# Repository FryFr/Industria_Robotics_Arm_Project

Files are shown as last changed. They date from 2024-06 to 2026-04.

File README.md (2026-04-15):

# 🦾 6-DoF Industrial Robotic Arm — Design, Simulation & Control

<div align="center">










**Full-pipeline research project for the design, 3D modeling, kinematic analysis, ROS simulation, and physical construction of a 6-Degrees-of-Freedom robotic arm with a gear-actuated gripper, capable of object pick-and-place operations.**

[Kinematic Model](#-kinematic-model--denavit-hartenberg-analysis) · [URDF Specification](#-urdf-model-specification) · [Arduino Control](#-arduino-control-system) · [Simulation](#-ros--gazebo-simulation) · [Hardware](#-hardware-components) · [Repository Structure](#-repository-structure)

</div>

---

## 📋 Table of Contents

- [Project Overview](#-project-overview)
- [Academic Context](#-academic-context)
- [System Architecture](#-system-architecture)
- [Mechanical Design — SolidWorks](#-mechanical-design--solidworks)
- [Physical Components Breakdown](#-physical-components-breakdown)
- [Kinematic Model — Denavit-Hartenberg Analysis](#-kinematic-model--denavit-hartenberg-analysis)
- [URDF Model Specification](#-urdf-model-specification)
- [Joint Parameters & Motion Limits](#-joint-parameters--motion-limits)
- [Link Inertial Properties](#-link-inertial-properties)
- [Gripper Mechanism](#-gripper-mechanism)
- [ROS & Gazebo Simulation](#-ros--gazebo-simulation)
- [Arduino Control System](#-arduino-control-system)
- [PCA9685 PWM Servo Driver](#-pca9685-pwm-servo-driver)
- [Control Sequence & Automation](#-control-sequence--automation)
- [Inverse Kinematics](#-inverse-kinematics)
- [Hardware Components](#-hardware-components)
- [Repository Structure](#-repository-structure)
- [Setup & Installation](#-setup--installation)
- [Roadmap](#-roadmap)
- [Contributing](#-contributing)
- [Author](#-author)
- [License](#-license)

---

## 🤖 Project Overview

This repository contains the complete engineering deliverables for the design, simulation, and physical construction of a **6-Degrees-of-Freedom (6-DoF) robotic manipulator arm** equipped with a gear-actuated parallel gripper. The project spans the full development pipeline:

1. **CAD modeling** — Each structural component was individually modeled in SolidWorks, with formal engineering drawings and PDF documentation
2. **Kinematic analysis** — Forward kinematics derived using the Denavit-Hartenberg (DH) convention; inverse kinematics formulated analytically
3. **URDF generation** — The SolidWorks assembly was exported to URDF format using the `sw_urdf_exporter` plugin, preserving mesh geometry, inertial tensors, joint axes, and motion limits
4. **ROS simulation** — The URDF model is integrated into ROS with launch files for both RViz visualization and Gazebo physics simulation
5. **Embedded control** — An Arduino UNO + PCA9685 system drives 5 servomotors over I2C with a serial-command automation interface

The arm is designed for **pick-and-place operations** on objects at known workspace locations, controlled via predefined joint-space trajectories.

URDF Visualization

---

## 🎓 Academic Context

| Field | Detail |
|---|---|
| **Course** | Robotics |
| **Institution** | Universidad EAN |
| **Supervisor** | Prof. Nikolay Prieto, Ph.D. |
| **Submission Date** | June 10th, 2024 |
| **Project Type** | Research & Engineering Final Project |

---

## 🏗 System Architecture

```
┌────────────────────────────────────────────────────────────────────┐
│                      FULL SYSTEM PIPELINE                          │
│                                                                    │
│  ┌──────────────┐    ┌──────────────┐    ┌──────────────────────┐  │
│  │  SolidWorks  │───▶│ URDF Export  │───▶│   ROS / Gazebo       │  │
│  │  CAD Model   │    │ sw_urdf v1.6 │    │  RViz + MoveIt       │  │
│  └──────────────┘    └──────────────┘    └──────────────────────┘  │
│                                                                    │
│  ┌──────────────┐    ┌──────────────┐    ┌──────────────────────┐  │
│  │  DH Analysis │───▶│  Kinematics  │───▶│   Joint Trajectories │  │
│  │  (Forward)   │    │  (Inverse)   │    │   & Path Planning    │  │
│  └──────────────┘    └──────────────┘    └──────────────────────┘  │
│                                                                    │
│  ┌──────────────┐    ┌──────────────┐    ┌──────────────────────┐  │
│  │  Arduino UNO │───▶│   PCA9685    │───▶│  5× Servo Motors     │  │
│  │  Serial I/O  │    │  I2C PWM     │    │  MG996R + SG90       │  │
│  └──────────────┘    └──────────────┘    └──────────────────────┘  │
└────────────────────────────────────────────────────────────────────┘
```

---

## 🔩 Mechanical Design — SolidWorks

The mechanical design phase used **SolidWorks** to model every structural component from scratch, producing precise digital models that served as manufacturing inputs for 3D printing.

### Individual Part Inventory

| SolidWorks Part | URDF Link | Physical Role |
|---|---|---|
| `BaseCentral.SLDPRT` | `base_link` | Fixed base, anchors the full kinematic chain |
| `Hombro.SLDPRT` | `Link_1` | Shoulder — full 360° rotation on vertical axis |
| `Brazo.SLDPRT` | `Link_2` | Upper arm — elevation from shoulder |
| `Codo.SLDPRT` | `Link_3` | Elbow — bends arm toward target |
| `Mano1.SLDPRT` | `Link_4` | Wrist roll — full 360° rotation |
| `Mano2.SLDPRT` | `Link_5` | Wrist pitch — orients end-effector |
| `Gripper base mano3.SLDPRT` | `Link_6` | Gripper mount — connects wrist to gripper |
| `gear1.SLDPRT` | `Gear_1` | Gripper drive gear — left finger actuator |
| `gear2.SLDPRT` | `Gear_2` | Gripper driven gear — right finger actuator |
| `Gripper 1.SLDPRT` | — | Finger structure |
| `grip link 1.SLDPRT` | — | Finger linkage |
| `Servo Motor MG996R.SLDPRT` | — | High-torque joint actuator (modeled) |
| `Servo Motor Micro 9g.SLDPRT` | — | Lightweight joint actuator (modeled) |

### Assembly Files

| Assembly | Contents |
|---|---|
| `Ensamble.SLDASM` | Primary arm assembly (base to wrist) |
| `Ensamble2.SLDASM` | Full assembly including gripper |
| `EnsamblePinza.SLDASM` | Isolated gripper sub-assembly with gears |

### Engineering Drawings

All parts have formal 2D engineering drawings available in two formats:

- **SolidWorks Drawings** (`.SLDDRW`) — Full parametric drawings with dimensions, tolerances and views
- **PDF Drawings** — Exported static drawings for reference and printing

Available drawings: `BaseCentral`, `Brazo`, `Codo`, `Hombro`, `Mano1`, `Mano2`, `gear1`, `gear2`, `Gripper 1`, `Gripper base mano3`, `grip link 1`, `Ensamble1_brazo` (sub-assembly), `Ensamble_explosionado_robot` (exploded view of full robot).

> 🔧 The exploded view (`Ensamble_explosionado_robot.pdf`) is particularly useful for understanding assembly order and fastener placement.

### 3D Printing

All structural parts were manufactured using **FDM (Fused Deposition Modeling) 3D printing** with **PLA (Polylactic Acid)** filament. PLA was selected for its:
- Low warping during printing
- Sufficient structural rigidity for low-load robotic applications
- Ease of post-processing
- Biodegradable properties

The SolidWorks parts were exported to STL format (the same STL meshes used in the URDF), ensuring dimensional consistency between the CAD model, the simulation, and the physical prototype.

Physical Assembly

---

## 📐 Kinematic Model — Denavit-Hartenberg Analysis

The forward kinematics of the arm were derived using the **Denavit-Hartenberg (DH) convention**, which provides a systematic 4-parameter representation of the transformation between consecutive joint frames.

### Why DH over Trigonometric Analysis?

Trigonometric position equations and direct Cartesian formulations are viable for 2- or 3-DoF systems. However, for a 6-DoF manipulator, the complexity of coupled rotations and translations makes these approaches intractable. The DH convention reduces each inter-frame transformation to a product of four elementary operations:

```
T(i-1→i) = Rot_z(θᵢ) · Trans_z(dᵢ) · Trans_x(aᵢ) · Rot_x(αᵢ)
```

Where:
- **θᵢ** — joint angle (rotation around z-axis, variable for revolute joints)
- **dᵢ** — link offset (translation along z-axis)
- **aᵢ** — link length (translation along x-axis)
- **αᵢ** — link twist (rotation around x-axis)

### DH Frame Assignment Convention

1. Frame 0 was fixed to the world/base and assigned to the first joint axis
2. Subsequent frames (1–6) were positioned following the DH rules, strictly avoiding pure rotations or translations about the Y-axis (which would require a modified DH formulation)
3. The final frame (Frame 6) coincides with the end-effector at the gripper center

### DH Table

Based on the URDF joint origins and axes, the DH parameters for the 6 main joints are:

| Joint | θᵢ (variable) | dᵢ (m) | aᵢ (m) | αᵢ (rad) | Type |
|---|---|---|---|---|---|
| Joint_1 | θ₁ | 0.0465 | 0.0308 | 0 | Revolute |
| Joint_2 | θ₂ | 0.1150 | 0.0011 | π/2 | Revolute |
| Joint_3 | θ₃ | 0 | 0.1000 | 0 | Revolute |
| Joint_4 | θ₄ | 0.0818 | 0.0001 | -π/2 | Revolute |
| Joint_5 | θ₅ | 0.0215 | 0 | -π/2 | Revolute |
| Joint_6 | θ₆ | 0 | 0.0350 | -π/2 | Revolute |

> Values extracted from URDF joint `<origin>` tags. The full homogeneous transformation matrix T(0→6) = T₁ · T₂ · T₃ · T₄ · T₅ · T₆ gives the end-effector pose in the base frame.

### Forward Kinematics

The full forward kinematic chain resolves to:

```
T(base→EE) = T₁(θ₁) × T₂(θ₂) × T₃(θ₃) × T₄(θ₄) × T₅(θ₅) × T₆(θ₆)
```

This yields a **4×4 homogeneous transformation matrix** encoding the end-effector position (x, y, z) and orientation (R₃ₓ₃ rotation matrix) in the world frame.

DH Frame Diagram

---

## 📄 URDF Model Specification

The URDF was automatically generated from the SolidWorks assembly using the **`sw_urdf_exporter` plugin v1.6.0-4-g7f85cfe (Build 1.6.7995.38578)** by Stephen Brawner.

The model file is located at:
```
1.Software/Ensamblaje_urdf/urdf/Ensamblaje_urdf.urdf
```

### Link Tree

```
base_link
└── Link_1        (Joint_1  — revolute, z-axis)
    └── Link_2    (Joint_2  — revolute, z-axis, limited ±30°)
        └── Link_3  (Joint_3 — revolute, z-axis)
            └── Link_4  (Joint_4 — revolute, z-axis, full)
                └── Link_5  (Joint_5 — revolute, z-axis)
                    └── Link_6  (Joint_6 — revolute, z-axis, full)
                        ├── Gear_1  (joint_gear1 — revolute, y-axis, ±30°)
                        └── Gear_2  (Joint_gear2 — revolute, y-axis, ±30°)
```

### STL Mesh Files

All meshes reside in `1.Software/Ensamblaje_urdf/meshes/`:

| Mesh File | Link | Approx. Size |
|---|---|---|
| `base_link.STL` | base_link | 108 KB |
| `Link_1.STL` | Link_1 (Shoulder) | 114 KB |
| `Link_2.STL` | Link_2 (Upper arm) | 104 KB |
| `Link_3.STL` | Link_3 (Elbow) | 54 KB |
| `Link_4.STL` | Link_4 (Wrist roll) | 55 KB |
| `Link_5.STL` | Link_5 (Wrist pitch) | 23 KB |
| `Link_6.STL` | Link_6 (Gripper mount) | 33 KB |
| `Gear_1.STL` | Gear_1 (Left gripper) | 69 KB |
| `Gear_2.STL` | Gear_2 (Right gripper) | 64 KB |

All meshes use the visual/collision color `rgba(0.792, 0.820, 0.933, 1.0)` — a light steel blue.

---

## 📊 Joint Parameters & Motion Limits

The following table consolidates all joint data extracted directly from the URDF:

| Joint | Type | Parent → Child | Origin (x, y, z) m | Origin (r, p, y) rad | Axis | Lower (rad) | Upper (rad) | Range (°) | Friction |
|---|---|---|---|---|---|---|---|---|---|
| `Joint_1` | revolute | base → Link_1 | (0.031, -0.097, 0.047) | (0, 0, π/2) | Z | -3.141 | 3.141 | 360° | 0.1 |
| `Joint_2` | revolute | Link_1 → Link_2 | (-0.001, -0.019, 0.115) | (π/2, 0, -0.057) | Z | -0.524 | 0.524 | 60° | 0.1 |
| `Joint_3` | revolute | Link_2 → Link_3 | (0, 0.100, 0) | (0, 0, π/2) | Z | -1.570 | 0.349 | 110° | 0.1 |
| `Joint_4` | revolute | Link_3 → Link_4 | (0.000, 0.082, 0.006) | (-π/2, 0, 0) | Z | -3.141 | 3.141 | 360° | 0.1 |
| `Joint_5` | revolute | Link_4 → Link_5 | (0, -0.008, 0.022) | (-π/2, 0, -π) | Z | -3.141 | 0.174 | 190° | 0.1 |
| `Joint_6` | revolute | Link_5 → Link_6 | (0.035, -0.000, -0.008) | (-π/2, 0, -π/2) | Z | -3.141 | 3.141 | 360° | 0.1 |
| `joint_gear1` | revolute | Link_6 → Gear_1 | (-0.014, 0.002, 0.023) | (0, 0, 0) | Y | -0.523 | 0.523 | 60° | — |
| `Joint_gear2` | revolute | Link_6 → Gear_2 | (0.013, -0.003, 0.023) | (0, 0, 0) | Y | -0.523 | 0.523 | 60° | — |

### Total Workspace DoF

- **6 active joints** (Joint_1 through Joint_6) — full arm positioning and orientation
- **2 gripper joints** (joint_gear1 + Joint_gear2) — parallel gear-actuated gripper
- **Total: 8 revolute joints** in the kinematic chain

### Servo-to-Joint Mapping (Physical)

| PCA9685 Channel | Physical Joint | SolidWorks Link | Servo Model | Angle Limit |
|---|---|---|---|---|
| Servo 0 | Base rotation | base_link ↔ Link_1 | MG996R | 0° – 180° |
| Servo 1 | Shoulder elevation | Link_1 ↔ Link_2 | MG996R | 0° – 85° |
| Servo 2 | Elbow flex | Link_2 ↔ Link_3 | MG996R | 0° – 90° |
| Servo 3 | Wrist pitch | Link_3 ↔ Link_4 | SG90 | 2° – 90° |
| Servo 4 | Gripper open/close | Gear_1 + Gear_2 | SG90 | 0° – 80° |

---

## ⚖️ Link Inertial Properties

Inertial data was computed directly by SolidWorks from the PLA density and exported to the URDF. These values are used by Gazebo for realistic physics simulation.

| Link | Mass (kg) | CoM X (m) | CoM Y (m) | CoM Z (m) | Ixx (kg·m²) | Iyy (kg·m²) | Izz (kg·m²) |
|---|---|---|---|---|---|---|---|
| base_link | 0.09282 | 0.03222 | -0.09726 | 0.06830 | 1.236e-4 | 1.267e-4 | 2.077e-4 |
| Link_1 | 0.10004 | 0.00279 | -0.01420 | 0.07333 | 1.228e-4 | 1.201e-4 | 1.071e-4 |
| Link_2 | 0.03836 | 0.00023 | 0.04485 | -0.00621 | 4.759e-5 | 5.827e-6 | 5.167e-5 |
| Link_3 | 0.02286 | 0.00070 | 0.02860 | 0.00472 | 1.938e-5 | 4.279e-6 | 2.256e-5 |
| Link_4 | 0.01138 | ~0 | -0.01420 | 0.00948 | 2.517e-6 | 2.816e-6 | 1.653e-6 |
| Link_5 | 0.01079 | 0.02085 | -0.00257 | -0.00310 | 1.978e-6 | 2.552e-6 | 3.258e-6 |
| Link_6 | 0.01024 | -0.00420 | 0.00847 | 0.01757 | 1.703e-6 | 3.123e-6 | 1.667e-6 |
| Gear_1 | 0.00933 | -0.01598 | 0.00255 | 0.02202 | 1.711e-6 | 2.285e-6 | 6.491e-7 |
| Gear_2 | 0.00938 | 0.01667 | 0.00652 | 0.02210 | 1.730e-6 | 2.285e-6 | 6.304e-7 |
| **Total** | **~0.336 kg** | — | — | — | — | — | — |

> The **total estimated arm mass is ~336 g**, consistent with a lightweight 3D-printed PLA prototype. Link_1 (Shoulder) is the heaviest link at 100 g.

---

## 🤏 Gripper Mechanism

The end-effector is a **gear-actuated parallel gripper** using a spur gear pair to synchronize the opening and closing of two finger assemblies:

### Gear Pair Specification

| Parameter | Gear_1 | Gear_2 |
|---|---|---|
| Parent Link | Link_6 | Link_6 |
| Origin offset | (-0.0139, 0.0015, 0.0225) | (0.013, -0.0025, 0.0225) |
| Rotation axis | Y | Y |
| Motion range | ±0.523 rad (±30°) | ±0.523 rad (±30°) |
| Mass | 9.33 g | 9.38 g |

### Gripper Sub-Assembly Components

The `EnsamblePinza.SLDASM` sub-assembly contains:
- `Gripper base mano3` — palm/base plate connecting to Link_6
- `Gripper 1` (×2) — finger bodies
- `grip link 1` (×4) — four-bar linkage elements connecting gears to fingers
- `gear1` + `gear2` — mating spur gear pair

The four-bar linkage mechanism converts the ±30° gear rotation into a symmetric lateral motion of both fingers, enabling **parallel jaw grasping**.

---

## 🖥 ROS & Gazebo Simulation

### Software Requirements

| Package | Version | Purpose |
|---|---|---|
| Ubuntu | 20.04 LTS | Operating system |
| ROS | Noetic (ROS 1) | Robot middleware and launch system |
| Gazebo | 11 | Physics simulation |
| RViz | 1.14+ | 3D visualization |
| `robot_state_publisher` | — | Broadcasts joint transforms (TF) |
| `joint_state_publisher_gui` | — | Interactive joint sliders in RViz |
| `sw_urdf_exporter` | 1.6.0 | SolidWorks → URDF export plugin |

> ⚠️ **Note:** The launch files use **ROS 1 (Noetic)** syntax (`roslaunch`, `<node pkg="...">`, `$(find ...)`). Despite references to ROS2 in the project documentation, the actual launch infrastructure is ROS 1.

### ROS Package Setup

```bash
# Create and build the workspace
mkdir -p ~/catkin_ws/src
cd ~/catkin_ws/src
# Copy the Ensamblaje_urdf package here
cp -r /path/to/Industria_Robotics_Arm_Project/1.Software/Ensamblaje_urdf .

cd ~/catkin_ws
catkin_make
source devel/setup.bash
```

### Launch — RViz Visualization

Visualize the arm with interactive joint sliders:

```bash
roslaunch Ensamblaje_urdf display.launch
```

This launches:
- `joint_state_publisher_gui` — GUI sliders for manually commanding each joint angle
- `robot_state_publisher` — Computes and broadcasts all link TF transforms from joint states
- `rviz` — 3D visualization with the robot model loaded

### Launch — Gazebo Physics Simulation

Spawn the arm in an empty Gazebo world:

```bash
roslaunch Ensamblaje_urdf gazebo.launch
```

This launches:
- `gazebo` (empty world)
- `spawn_model` — loads the URDF into Gazebo via `gazebo_ros`
- `tf_footprint_base` — static TF between `base_link` and `base_footprint`
- `fake_joint_calibration` — publishes `/calibrated` to unblock joint controllers

### Joint Names Configuration

The controller joint list is defined in `config/joint_names_Ensamblaje_urdf.yaml`:

```yaml
controller_joint_names: [
  '',           # placeholder
  'Joint_1',    # Shoulder rotation
  'Joint_2',    # Upper arm elevation
  'Joint_3',    # Elbow flexion
  'Joint_4',    # Wrist roll
  'Joint_5',    # Wrist pitch
  'Joint_6',    # End-effector rotation
  'joint_gear1', # Gripper left
  'Joint_gear2'  # Gripper right
]
```

### URDF Validation

Before launching, validate the URDF for kinematic and XML errors:

```bash
# Check URDF structure
check_urdf 1.Software/Ensamblaje_urdf/urdf/Ensamblaje_urdf.urdf

# Visualize link tree
urdf_to_graphiz 1.Software/Ensamblaje_urdf/urdf/Ensamblaje_urdf.urdf
evince Ensamblaje_urdf.pdf
```

---

## 🎮 Arduino Control System

### Architecture

```
PC / Host
   │
   │  Serial (USB, 9600 baud)
   ▼
Arduino UNO
   │
   │  I2C (SDA/SCL — pins A4/A5)
   ▼
PCA9685 (16-ch PWM Driver @ 0x40)
   │
   ├── Ch 0 — MG996R — Base rotation
   ├── Ch 1 — MG996R — Shoulder elevation
   ├── Ch 2 — MG996R — Elbow flexion
   ├── Ch 3 — SG90  — Wrist pitch
   └── Ch 4 — SG90  — Gripper
```

### Core Control Code — `Manual_Control.ino`

```cpp
#include <Wire.h>
#include <Adafruit_PWMServoDriver.h>

Adafruit_PWMServoDriver pwm;

// PWM pulse width range for servo control (in 12-bit counts @ 60 Hz)
const int SERVOMIN = 150;  // ~0.7 ms pulse  → 0°
const int SERVOMAX = 600;  // ~2.4 ms pulse  → 180°
```

### PWM Frequency & Pulse Width

The PCA9685 is configured at **60 Hz**, which is the standard PWM frequency for analog servomotors. The `SERVOMIN` and `SERVOMAX` counts correspond to:

```
Pulse width (µs) = count × (1 / (60 Hz × 4096)) × 10⁶
SERVOMIN (150) → 150 / (60 × 4096) × 1e6 ≈ 610 µs
SERVOMAX (600) → 600 / (60 × 4096) × 1e6 ≈ 2441 µs
```

The angle-to-pulse mapping:

```cpp
int pulseLength = map(angle, 0, 180, SERVOMIN, SERVOMAX);
pwm.setPWM(servo, 0, pulseLength);
```

---

## 🔧 PCA9685 PWM Servo Driver

The **PCA9685** is a 16-channel, 12-bit PWM driver from NXP/Adafruit that communicates over I2C. It offloads all servo timing from the Arduino, allowing deterministic PWM signals on up to 16 channels simultaneously.

| Parameter | Value |
|---|---|
| Communication | I2C (default address `0x40`) |
| Channels | 16 |
| Resolution | 12-bit (4096 steps per cycle) |
| PWM Frequency | Configurable 40–1000 Hz (set to 60 Hz) |
| Arduino Pins | SDA → A4, SCL → A5 |
| Library | `Adafruit_PWMServoDriver` |
| Operating Voltage | 3.3V or 5V logic; servo power separate (V+) |

> ⚠️ **Important:** The PCA9685 V+ rail must be connected to an **external 5–6V DC power supply**, not the Arduino 5V pin. The MG996R servos draw up to 2.5A stall current each — powering them from the Arduino will cause brownouts and undefined behavior.

### I2C Wiring

```
Arduino UNO     PCA9685
-----------     -------
A4 (SDA)   ──── SDA
A5 (SCL)   ──── SCL
5V         ──── VCC (logic)
GND        ──── GND
           ──── V+  ←── External 5V supply (+)
           ──── GND ←── External 5V supply (-)
```

---

## 🔄 Control Sequence & Automation

The firmware implements a **serial-triggered state machine**. The user sends single-character commands via the Serial Monitor:

| Command | Action |
|---|---|
| `Y` or `y` | Start pick-and-place automation sequence |
| `S` or `s` | Stop and hold current position |

### Predefined Motion Sequence

The `executeSequence()` function defines three joint-space waypoints:

```
POSITION 1 — Home (Initial)
   Servo 0: 90°  (base centered)
   Servo 1:  0°  (shoulder down)
   Servo 2:  0°  (elbow straight)
   Servo 3:  2°  (wrist neutral)
   Servo 4: 80°  (gripper open)

POSITION 2 — Object Pickup
   Servo 0: 90°  (base centered)
   Servo 1: 45°  (shoulder mid-elevation)
   Servo 2: 45°  (elbow bent)
   Servo 3: 45°  (wrist angled)
   Servo 4:  0°  (gripper closed → grips object)

POSITION 3 — Destination
   Servo 0: 150° (base rotated to drop zone)
   Servo 1: 20°  (shoulder lowered)
   Servo 2: 20°  (elbow extended)
   Servo 3: 20°  (wrist adjusted)
   Servo 4: 80°  (gripper open → releases object)

→ Returns to POSITION 1 (Home)
```

Each position is held for **1000 ms** before transitioning to the next waypoint.

### Per-Joint Angle Limits (Firmware)

These software limits are enforced independently of the hardware/URDF limits:

| Channel | Joint | Min (°) | Max (°) | Notes |
|---|---|---|---|---|
| 0 | Base | 0 | 180 | Full servo range |
| 1 | Shoulder | 0 | 85 | Mechanically constrained |
| 2 | Elbow | 0 | 90 | Mechanically constrained |
| 3 | Wrist pitch | 2 | 90 | Offset to avoid singularity at 0° |
| 4 | Gripper | 0 | 80 | 0° = closed, 80° = open |

---

## 🧮 Inverse Kinematics

The `1.Software/Invers_Kinematics/` directory is reserved for inverse kinematics computation. The analytical IK problem for a 6-DoF spherical-wrist manipulator can be decoupled into:

1. **Positional IK** (Joints 1–3): Determines the shoulder, elbow, and base angles to position the wrist center at the desired 3D location
2. **Orientational IK** (Joints 4–6): Determines the wrist Euler angles to achieve the desired end-effector orientation

### Analytical Approach (Spherical Wrist Decoupling)

For a robot with a spherical wrist (Joints 4, 5, 6 intersecting at a single point), the IK decouples as:

```
Step 1 — Compute wrist center position:
   Pw = Pd - d₆ · R_desired · [0, 0, 1]ᵀ

Step 2 — Solve for θ₁, θ₂, θ₃ geometrically:
   θ₁ = atan2(Pw_y, Pw_x)
   Use law of cosines for θ₂, θ₃ given link lengths a₂, a₃

Step 3 — Solve for θ₄, θ₅, θ₆:
   R₃₆ = (R₀₃)ᵀ · R_desired
   Extract Euler angles from R₃₆
```

> 📌 **Note:** The `Invers_Kinematics/Sample.txt` placeholder indicates this module is planned for future implementation. Contributions implementing the analytical IK are welcome — see [Contributing](#-contributing).

---

## 🧰 Hardware Components

| Component | Model | Qty | Role |
|---|---|---|---|
| Microcontroller | Arduino UNO | 1 | Main controller, serial interface |
| PWM Driver | PCA9685 (Adafruit) | 1 | 16-channel I2C servo controller |
| High-torque servo | MG996R | 3 | Joints 0–2 (base, shoulder, elbow) |
| Micro servo | SG90 (9g) | 2 | Joints 3–4 (wrist, gripper) |
| DC Power Supply | 5–6V, 3A+ | 1 | Servo power (external) |
| PLA Filament | 1.75mm PLA | ~250g | 3D printing all structural parts |
| Fasteners | M2/M3 screws+nuts | Assorted | Part assembly |
| Jumper wires | M-M, M-F | ~20 | Electronic connections |
| Protoboard | Full-size | 1 | Component layout |

### Servo Comparison

| Spec | MG996R | SG90 |
|---|---|---|
| Stall Torque | 9.4 kg·cm (6V) | 1.8 kg·cm (5V) |
| Operating Voltage | 4.8–7.2V | 4.8–6V |
| Speed | 0.19 s/60° | 0.1 s/60° |
| Weight | 55 g | 9 g |
| Gear Type | Metal | Plastic/nylon |
| Use in project | Primary joints (high load) | Wrist + gripper (low load) |

---

## 📁 Repository Structure

```
Industria_Robotics_Arm_Project/
│
├── 0.Model/
│   ├── 0.0. Individual Parts/          # SolidWorks part files (.SLDPRT)
│   │   ├── BaseCentral.SLDPRT          # Base link
│   │   ├── Hombro.SLDPRT              # Shoulder (Link_1)
│   │   ├── Brazo.SLDPRT               # Upper arm (Link_2)
│   │   ├── Codo.SLDPRT                # Elbow (Link_3)
│   │   ├── Mano1.SLDPRT               # Wrist roll (Link_4)
│   │   ├── Mano2.SLDPRT               # Wrist pitch (Link_5)
│   │   ├── Gripper base mano3.SLDPRT  # Gripper mount (Link_6)
│   │   ├── Gripper 1.SLDPRT           # Finger body
│   │   ├── grip link 1.SLDPRT         # Finger linkage
│   │   ├── gear1.SLDPRT               # Drive gear
│   │   ├── gear2.SLDPRT               # Driven gear
│   │   ├── Servo Motor MG996R.SLDPRT  # High-torque servo (model)
│   │   └── Servo Motor Micro 9g.SLDPRT # Micro servo (model)
│   │
│   ├── 0.1. Assembly/
│   │   ├── Ensamble.SLDASM             # Main arm assembly
│   │   ├── Ensamble2.SLDASM            # Full assembly with gripper
│   │   └── EnsamblePinza.SLDASM        # Gripper sub-assembly
│   │
│   └── 0.2. Sketch/
│       ├── PDF Drawings/               # Engineering drawings (PDF, 13 sheets)
│       └── SolidWorks Drawings/        # Parametric drawings (.SLDDRW)
│
├── 1.Software/
│   ├── Ensamblaje_urdf/                # ROS URDF package
│   │   ├── urdf/
│   │   │   ├── Ensamblaje_urdf.urdf    # Full robot URDF (9 links, 8 joints)
│   │   │   └── Ensamblaje_urdf.csv     # DH/inertial data export from SolidWorks
│   │   ├── meshes/                     # STL collision/visual meshes (9 files)
│   │   ├── launch/
│   │   │   ├── display.launch          # RViz + joint_state_publisher_gui
│   │   │   └── gazebo.launch           # Gazebo physics simulation
│   │   ├── config/
│   │   │   └── joint_names_Ensamblaje_urdf.yaml  # Controller joint list
│   │   ├── CMakeLists.txt
│   │   └── package.xml
│   │
│   ├── Manual_Control/
│   │   └── Manual_Control.ino          # Arduino firmware (PCA9685 + serial)
│   │
│   └── Invers_Kinematics/              # IK solver (placeholder — future work)
│
├── 2. Documents/
│   └── Proyecto Robótica.docx          # Full research document
│
└── README.md
```

---

## ⚙️ Setup & Installation

### Prerequisites

| Tool | Version | Installation |
|---|---|---|
| Ubuntu | 20.04 LTS | — |
| ROS Noetic | 1.15+ | [ros.org/install](http://wiki.ros.org/noetic/Installation/Ubuntu) |
| Gazebo | 11 | Included with `ros-noetic-desktop-full` |
| Arduino IDE | 1.8+ | [arduino.cc/downloads](https://www.arduino.cc/en/software) |
| SolidWorks | 2022+ | Commercial license required |

### ROS Environment Setup

```bash
# 1. Install ROS Noetic (full desktop)
sudo apt update
sudo apt install ros-noetic-desktop-full

# 2. Install additional packages
sudo apt install ros-noetic-joint-state-publisher-gui \
                 ros-noetic-robot-state-publisher \
                 ros-noetic-gazebo-ros-pkgs \
                 ros-noetic-xacro

# 3. Create catkin workspace
mkdir -p ~/catkin_ws/src
cd ~/catkin_ws/src

# 4. Clone the repository
git clone https://github.com/FryFr/Industria_Robotics_Arm_Project.git

# 5. Copy ROS package to src
cp -r Industria_Robotics_Arm_Project/1.Software/Ensamblaje_urdf .

# 6. Build
cd ~/catkin_ws
catkin_make
source devel/setup.bash
```

### Arduino Setup

```bash
# Install Adafruit PWM Servo Driver library
# In Arduino IDE: Tools → Manage Libraries → Search "Adafruit PWM Servo Driver"
# OR via CLI:
arduino-cli lib install "Adafruit PWM Servo Driver Library"
```

Open `1.Software/Manual_Control/Manual_Control.ino`, select **Arduino UNO** as the board, select the correct COM port, and upload. Use the **Serial Monitor at 9600 baud** to send `Y`/`S` commands.

### Running the Simulation

```bash
# Terminal 1 — Start ROS master
roscore

# Terminal 2 — RViz visualization (interactive joint sliders)
roslaunch Ensamblaje_urdf display.launch

# OR Terminal 2 — Gazebo physics simulation
roslaunch Ensamblaje_urdf gazebo.launch
```

---

## 🗺 Roadmap

- [ ] **Inverse kinematics solver** — Implement analytical IK using spherical wrist decoupling in the `Invers_Kinematics/` module
- [ ] **MoveIt! integration** — Configure MoveIt! for motion planning, collision avoidance, and trajectory execution
- [ ] **ROS2 migration** — Port launch files and controllers to ROS2 (Humble or Iron)
- [ ] **Closed-loop control** — Add joint encoders or potentiometers for position feedback
- [ ] **Vision-guided grasping** — Integrate an RGB-D camera (RealSense or ZED) with OpenCV/PCL for object detection
- [ ] **URDF → SDF conversion** — Improve Gazebo simulation with proper SDF dynamics
- [ ] **Trajectory interpolation** — Replace discrete waypoints with smooth cubic spline joint trajectories
- [ ] **Web dashboard** — Real-time joint monitoring and commanding via ROS Bridge + WebSocket

---

## 🤝 Contributing

Contributions are welcome, especially for:

- Implementing the analytical **Inverse Kinematics** module (Python or C++)
- Migrating the launch system to **ROS2**
- Adding **MoveIt!** configuration files
- Improving servo **calibration** or adding encoder feedback

To contribute:

1. **Fork** this repository
2. Create your feature branch:
   ```bash
   git checkout -b feature/inverse-kinematics
   ```
3. Commit with descriptive messages:
   ```bash
   git commit -m "feat(ik): implement analytical inverse kinematics with spherical wrist decoupling"
   ```
4. Push and open a **Pull Request**

### Commit Convention

| Prefix | Scope | Usage |
|---|---|---|
| `feat` | `(ik)`, `(urdf)`, `(ctrl)` | New functionality |
| `fix` | — | Bug fix |
| `sim` | `(gazebo)`, `(rviz)` | Simulation changes |
| `hw` | `(servo)`, `(arduino)` | Hardware/firmware changes |
| `docs` | — | Documentation only |
| `cad` | `(solidworks)` | CAD model changes |

---

## 👨‍💻 Author

**Juan Silva Medina**
- GitHub: [@FryFr](https://github.com/FryFr)
- LinkedIn: [linkedin.com/in/jsilva-medina](https://www.linkedin.com/in/jsilva-medina/?skipRedirect=true)
- YouTube: [@juansilva4256](https://www.youtube.com/@juansilva4256)

**Academic Supervisor:** Prof. Nikolay Prieto, Ph.D. — Universidad EAN

---

## 📄 License

Distributed under the **MIT License**. See [`LICENSE`](./LICENSE) for more details.

```
MIT License — Copyright (c) 2024 Juan Silva Medina
```

---

## 📚 References

- Denavit, J. & Hartenberg, R.S. (1955). *A kinematic notation for lower-pair mechanisms based on matrices.* Journal of Applied Mechanics, 22(2), 215–221.
- Craig, J.J. (2005). *Introduction to Robotics: Mechanics and Control* (3rd ed.). Pearson Prentice Hall.
- Siciliano, B. et al. (2009). *Robotics: Modelling, Planning and Control.* Springer.
- ROS Wiki — [URDF Tutorials](http://wiki.ros.org/urdf/Tutorials)
- Adafruit PCA9685 — [Product Guide](https://learn.adafruit.com/16-channel-pwm-servo-driver)
- Brawner, S. — [SolidWorks to URDF Exporter](http://wiki.ros.org/sw_urdf_exporter)

---

<div align="center">
  <sub>Built with ❤️, SolidWorks, ROS and a lot of PLA · Found it useful? Give it a ⭐</sub>
</div>

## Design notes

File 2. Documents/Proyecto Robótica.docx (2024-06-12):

PROYECTO DE ROBÓTICA: CONSTRUCCIÓN Y APLICACIÓN DE LA CINEMÁTICA INVERSA A UN BRAZO ROBOT DE SEIS GRADOS DE LIBERTAD UTILIZANDO ROS2

MATEO GUZMÁN SALAZAR

JUAN SEBASTIÁN SILVA MEDINA

DANIEL JOSE MARTINEZ ACEVEDO

RUBER ANDREW MIURA MONTERO

UNIVERSIDAD EAN

ROBÓTICA INDUSTRIAL

EDWIN NIKOLAY PRIETO PARRADO

BOGOTÁ D.C

08 DE JUNIO 202

# Introducción

# Revisión de la literatura

# Diseño del sistema

# Análisis cinemático

El desarrollo del análisis cinemático requiere del uso de un algoritmo que permita describir la posición del efector final del robot (pinza) con respecto a la base o tierra del robot, el cual se mantiene invariante y se considera un sistema de referencia fijo. Para el análisis cinemático del robot se procedió a emplear una vista general del diseño en SolidWorks, como se puede observar en la figura #. Esta vista permite obtener información gráfica de los componentes del robot facilitar el análisis matemático.

###### Figura #

Vista general del brazo robot en SolidWorks.

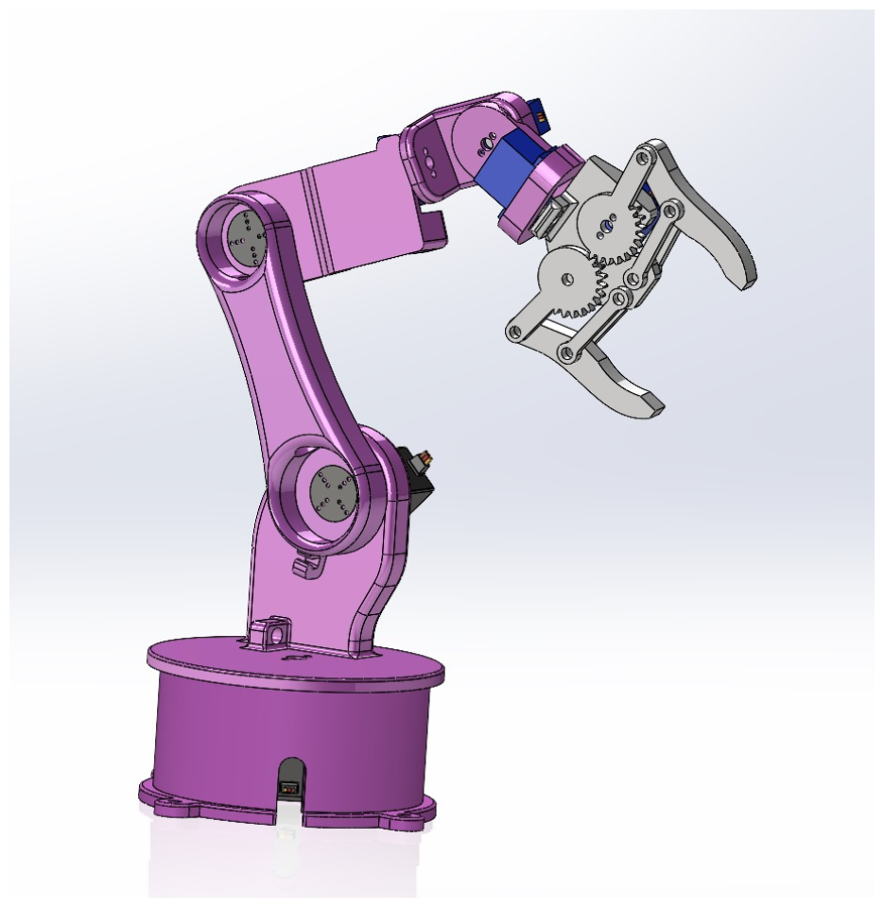
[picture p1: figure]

###### Nota. La vista general permite observar todos los actuadores y eslabones del robot de forma compacta.

Con base en la vista general es posible comenzar con el análisis cinemático, para ello se procede a dibujar un boceto con las vistas de perfil y alzado, como se puede observar en la figura #. Se decidió expresar las medidas en forma de variables ( H_n ,L_n , W_n ) tomando en cuenta que las dimensiones pueden presentar variaciones debido a las tolerancias de impresión y también por simplificación y claridad del dibujo.

###### Figura #

Vistas de perfil y alzado del robot

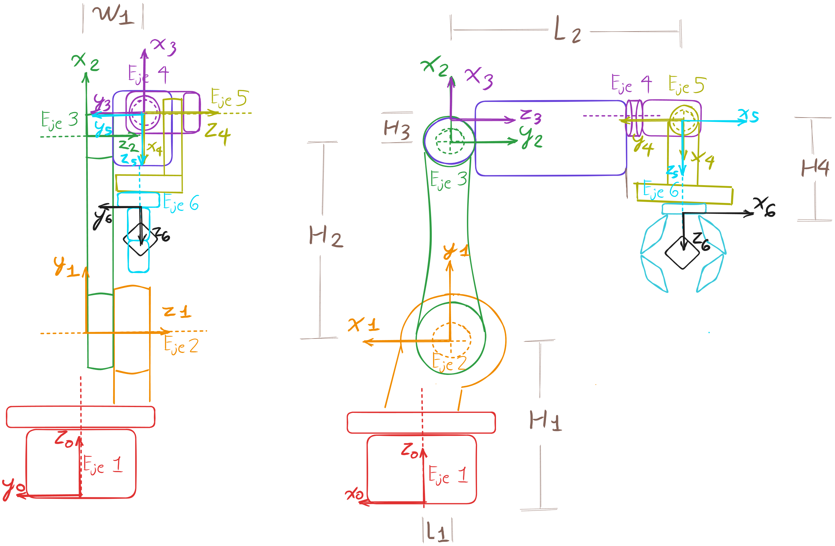
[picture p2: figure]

Nota. Elaboración propia.

Una vez creado el boceto del robot se procedió a aplicar el algoritmo de Denavit-Hartenberg, este algoritmo fue elegido puesto que es uno de los más eficientes al momento de encontrar la cinemática directa en robots manipuladores. Para ello, se estableció un sistema de referencia 0 y asignar aquí el eje 1, siguiendo el algoritmo se procedió a posicionar los demás sistemas de referencia de 1 a 6 hasta alcanzar el efector final, siempre evitando rotaciones y traslaciones puras en torno al eje y.

Cierto es que existen otras metodologías para encontrar la cinemática directa, como lo pueden ser el análisis trigonométrico y la formulación de ecuaciones de posición en las coordenadas x,y,z . Estas metodologías son adecuadas para la representación de robots de dos o tres grados de libertad, pero presentan dificultades al momento de analizar un mayor número de grados de libertad, como lo es el caso del presente robot.

Una vez obtenidos todos los sistemas de referencia del robot de 6 grados de libertad y definiendo las medidas en términos de variables es momento de proceder con la tabla de DH. Para completar esta tabla es necesario identificar: la rotación pura en z , traslación pura en z , traslación pura en x y rotación pura en x (en ese orden) de cada uno de los sistemas de referencia establecidos en relación el sistema siguiente. De esta forma se obtuvieron los datos reflejados en la tabla #.

###### Tabla #

Tabla de Denavit-Hartenberg para el robot de seis grados de libertad.

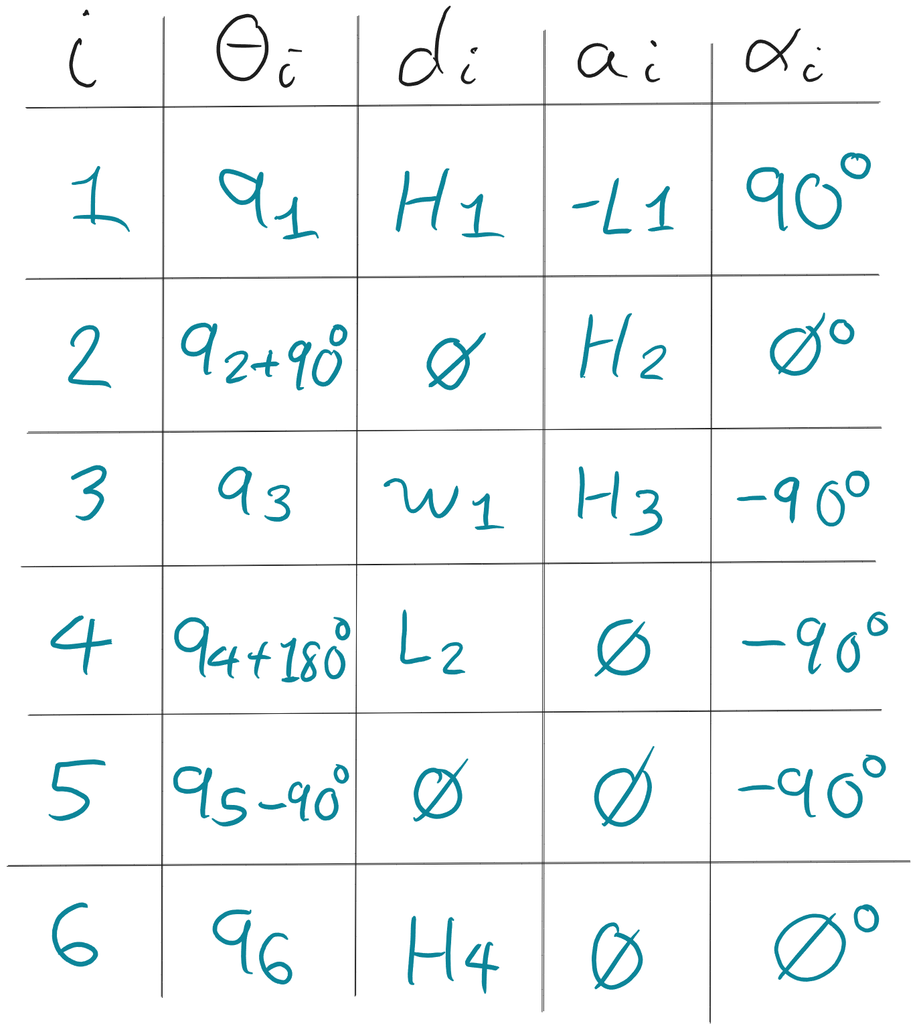
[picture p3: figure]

Nota. Elaboración propia.

# Ambiente de simulación

La construcción de este proyecto se llevó a cabo utilizando la tecnología de impresión 3D con material PLA. Este material, conocido por su versatilidad y durabilidad, fue fundamental para asegurar la calidad y resistencia de las piezas impresas. El proceso de impresión incluyó varias etapas, desde la configuración inicial de la impresora hasta la supervisión continua durante la impresión para garantizar que cada componente saliera según las especificaciones deseadas.

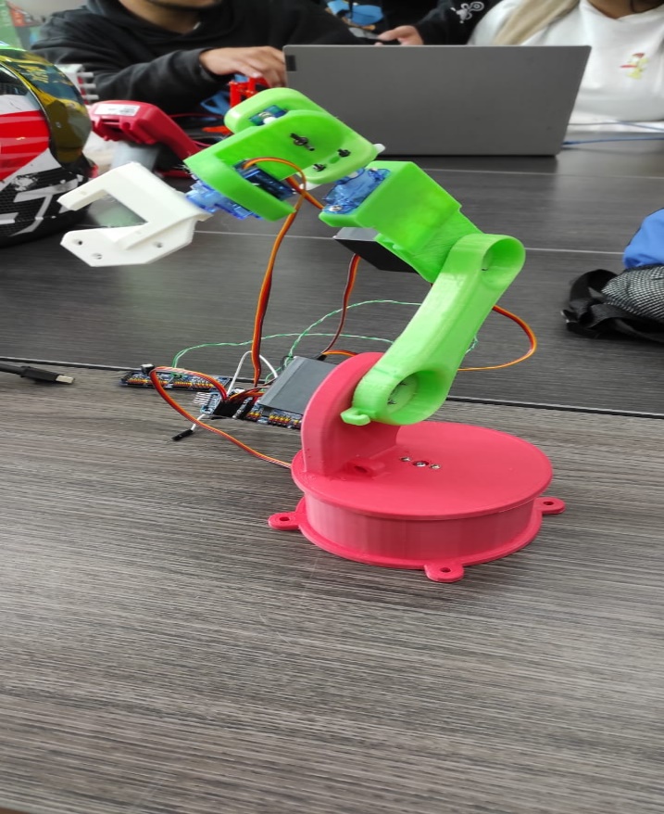
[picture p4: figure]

Para el movimiento y la funcionalidad del dispositivo, se emplearon un total de siete servos. Tres de ellos fueron modelos MG995, reconocidos por su potencia y precisión, especialmente adecuados para tareas que requieren un alto torque. Los otros cuatro servos fueron modelos SG90, más pequeños y ligeros, pero igualmente eficaces para tareas que no requieren tanta fuerza. Esta combinación de servos permitió un equilibrio entre potencia y eficiencia en el diseño final del proyecto.

Antes de la impresión, se realizó un diseño detallado utilizando el software SolidWorks. Este programa permitió crear modelos tridimensionales precisos de cada componente, asegurando que todas las piezas encajaran perfectamente al ensamblarlas. El diseño incluyó consideraciones para la colocación de los servos y otros componentes, así como las rutas para el cableado interno.

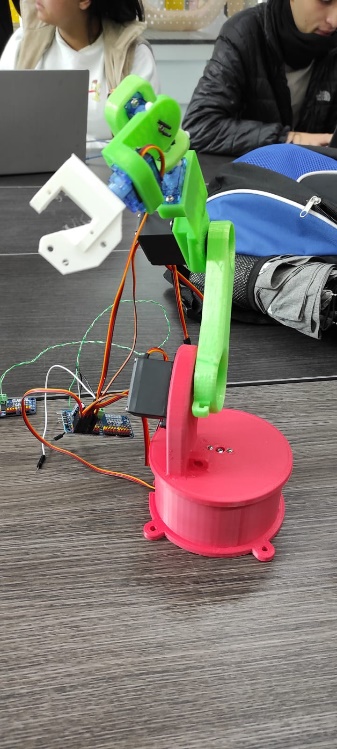
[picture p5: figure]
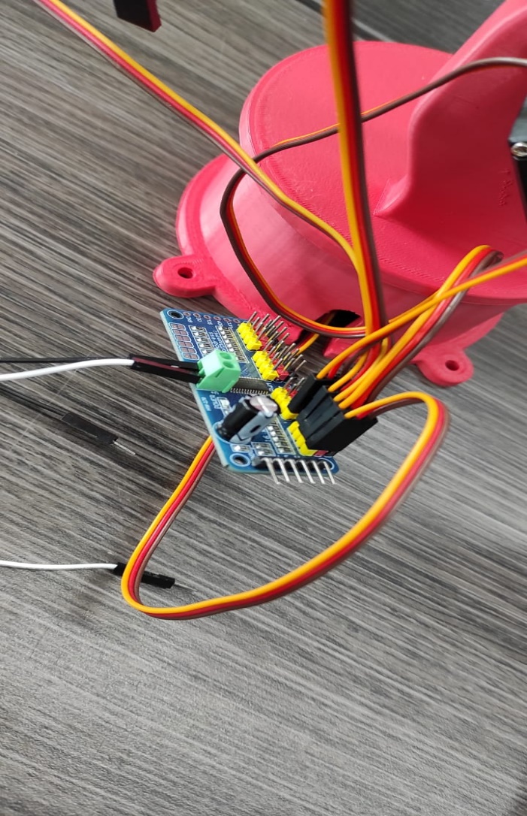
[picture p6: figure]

El ensamblaje de las piezas impresas se realizó utilizando tornillería M3 de diversas longitudes, seleccionadas para ajustarse a las necesidades específicas de cada unión. Esta tornillería aseguró una conexión robusta y estable entre las diferentes partes del dispositivo. Los servos se conectaron a un módulo PCA9685, un controlador PWM que permite manejar múltiples servos de manera eficiente. Este módulo es esencial para coordinar los movimientos precisos requeridos por el proyecto.

La comunicación entre el Arduino y el módulo PCA9685 se realizó a través de las entradas de reloj (clock) y datos (data), utilizando el protocolo I2C. Esta configuración facilitó el control sincronizado de los servos, permitiendo un rendimiento óptimo del sistema. Para alimentar el módulo PCA9685, se utilizó una fuente de alimentación externa capaz de proporcionar 5V con un máximo de 2 amperios, suficiente para garantizar un funcionamiento estable y sin interrupciones.

En resumen, la combinación de impresión 3D con PLA, el uso de servos MG995 y SG90, el diseño en SolidWorks, y el ensamblaje meticuloso con tornillería M3 y el módulo PCA9685, resultó en un proyecto funcional y bien diseñado. La alimentación externa adecuada y la comunicación eficiente entre los componentes electrónicos aseguraron que el dispositivo cumpliera con los requisitos esperados.

# Resultados

Tras aplicar el algoritmo de Denavit-Hartenberg (DH) al brazo robot de 6 grados de libertad, se obtuvieron los siguientes resultados:

Posicionamiento de los Sistemas de Referencia:

Se establecieron y posicionaron seis sistemas de referencia desde la base del robot hasta el efector final, asegurando la alineación adecuada conforme al algoritmo DH.

Parámetros de la Tabla DH:

Se identificaron los parámetros DH para cada uno de los sistemas de referencia, que incluyen:

Rotación pura en zzz

Traslación pura en zzz

Traslación pura en xxx

Rotación pura en xxx

La tabla resultante reflejó las transformaciones necesarias para cada eslabón en términos de estas operaciones.

# Discusión

El uso del algoritmo DH permitió una descripción clara y sistemática de la cinemática directa del robot, proporcionando una matriz de transformación homogénea que describe la posición y orientación del efector final respecto a la base del robot.

Ventajas del Algoritmo DH:

Eficiencia: El algoritmo DH es especialmente eficiente para robots con múltiples grados de libertad, como el presente caso de 6 DOF.

Simplicidad: La metodología proporciona una forma estructurada y simplificada de derivar las ecuaciones de transformación.

Limitaciones y Consideraciones:

Tolerancias de Impresión: Las dimensiones expresadas como variables (Hn,Ln,WnH_n, L_n, W_nHn ,Ln ,Wn ) tienen en cuenta las posibles variaciones debido a tolerancias de impresión. Esto es crucial para garantizar la precisión en aplicaciones prácticas.

Comparación con Otros Métodos: Aunque se consideraron otras metodologías, como el análisis trigonométrico y las ecuaciones de posición en coordenadas x,y,zx, y, zx,y,z, estas presentan dificultades para robots con más de tres grados de libertad. El algoritmo DH resultó ser más adecuado para este análisis.

# Conclusión

El análisis cinemático del brazo robot utilizando el algoritmo Denavit-Hartenberg proporcionó una solución efectiva y estructurada para describir la posición y orientación del efector final en relación con la base del robot. Los resultados obtenidos son fundamentales para el control y la programación del robot en diversas aplicaciones.

- Aplicabilidad: El método empleado es aplicable a una amplia gama de robots manipuladores, especialmente aquellos con múltiples grados de libertad.
- Precisión y Eficiencia: La combinación del diseño en SolidWorks y el algoritmo DH garantiza una alta precisión y eficiencia en el análisis cinemático.
- Futuras Mejoras: Para mejorar aún más la precisión, se recomienda considerar las tolerancias de fabricación e impresión en el diseño inicial y durante la aplicación del algoritmo.

En conclusión, el uso del algoritmo DH en el análisis cinemático de robots manipuladores es una práctica recomendada debido a su eficiencia, simplicidad y aplicabilidad en robots con múltiples grados de libertad.

# Referencias

Alan, D., & Cortez, L. (2018). Procesos y Fundamentos de la investigacion científica. In Journal of Chemical Information and Modeling (Vol. 53, Issue 9).

Alcaldía Mayor de Bogotá D.C. (2018). PASADO, PRESENTE Y FUTURO DE BOGOTÁ.

Altieri, M. A., Nicholls, C. I., Henao, A., & Lana, M. A. (2015). Agroecology and the design of climate change-resilient farming systems. In Agronomy for Sustainable Development (Vol. 35, Issue 3). https://doi.org/10.1007/s13593-015-0285-2

Ariffin Noordin, K., Chee Onn, C., & Faizal Ismail, M. (2006). A Low-Cost Microcontroller-based Weather Monitoring System. In Journal (Vol. 5, Issue 1).

Casas Anguita, J., Repullo Labrador, J. R., & Donado Campos, J. (2003). La encuesta como técnica de investigación. Elaboración de cuestionarios y tratamiento estadístico de los datos (I). Atención Primaria, 31(8). https://doi.org/10.1016/s0212-6567(03)70728-8

CREG. (2023). Tarifas de energía eléctrica ($/kWh) reguladas por la comisión de energía y gas (CREG). Enel.

Cvetković, A., Maguiña, J. L., Soto, Alonso., Lama-Valdivia, J., & Correa López, L. (2021). ESTUDIOS TRANSVERSALES Cross-sectional studies. Revista de La Facultad de Medicina Humana, 21(1).

FAO. (2002). El cultivo protegido en clima mediterráneo. Estudio FAO, Producción Y\nprotección Vegetal, 90.

Garaventa, D. (2015). Proyecto instalación de un invernadero inteligente. Universidad de Buenos Aires.

Gomathi, K., Balaji, A., Vijaya Shanthy, S., Jeevetha, T., Sanjay, & Mithil, J. (2022). Experimental investigation on IOT interfaced smart gardening system with human path clearance. Materials Today: Proceedings, 66. https://doi.org/10.1016/j.matpr.2022.05.298

Hernandez, R. (2020). Metodologia de la Investigacion - Sampieri (6ta edicion).pdf. McGRAW-HILL / INTERAMERICANA EDITORES, S.A. DE C.

Kiernan, B. M., Fay, C., Beirne, S., & Diamond, D. (2008). Development of an autonomous greenhouse gas monitoring system. Proceedings of World Academy of Science, Engineering and Technology, 34.

Malhi, G. S., Kaur, M., & Kaushik, P. (2021). Impact of climate change on agriculture and its mitigation strategies: A review. In Sustainability (Switzerland) (Vol. 13, Issue 3). https://doi.org/10.3390/su13031318

Montoya, E. A. Q., Colorado, S. F. J., Muñoz, W. Y. C., & Golondrino, G. E. C. (2017). Propuesta de una Arquitectura para Agricultura de Precisión Soportada en IoT. RISTI - Revista Iberica de Sistemas e Tecnologias de Informacao, 24. https://doi.org/10.17013/risti.24.39-56

Naga, V., & Gunturi, R. (2013). Micro Controller Based Automatic Plant Irrigation System. International Journal of Advancements in Research & Technology, 2(4).

Olawepo, S., Adebiyi, A., Adebiyi, M., & Okesola, O. (2020). An Overview of Smart Garden Automation. 2020 International Conference in Mathematics, Computer Engineering and Computer Science, ICMCECS 2020. https://doi.org/10.1109/ICMCECS47690.2020.240892

Penzenstadler, B., Khakurel, J., Plojo, C. J., Sanchez, M., Marin, R., & Tran, L. (2018). Resilient smart gardens-Exploration of a blueprint. Sustainability (Switzerland), 10(8). https://doi.org/10.3390/su10082654

Ramírez, L. J. (2021, September 19). Red de agricultoras y agricultores: la riqueza de las huertas urbanas en Bogotá. BOGOTA.

Secretaría Distrital de Ambiente. (2022, May 23). Huertas Urbanas: ¿Qué son y cuántas hay en Bogotá? Ovserbatorio Ambiental de Bogotá.

Selmani, A., Outanoute, M., Khayat, M. El, Guerbaoui, M., Ed-Dahhak, A., Lachhab, A., & Bouchikhi, B. (2019). Towards autonomous greenhouses solar-powered. Procedia Computer Science, 148. https://doi.org/10.1016/j.procs.2019.01.062

Veiga de Cabo, J., Fuente Díez, E. de la, & Zimmermann Verdejo, M. (2008). Modelos de estudios en investigación aplicada: conceptos y criterios para el diseño. Medicina y Seguridad Del Trabajo, 54(210). https://doi.org/10.4321/s0465-546x2008000100011

Velasco-Hemandez, G., Mirani, A. A., Awasthi, A., & Walsh, J. (2022). IoT-based system for monitoring conditions in an industrial painting booth. 2022 33rd Irish Signals and Systems Conference, ISSC 2022. https://doi.org/10.1109/ISSC55427.2022.9826206

Verbeek, M., & Hardeweg, B. (2022). From consumer to prosumer: Are small-scale home indoor farms economically viable? European Journal of Horticultural Science, 87(3). https://doi.org/10.17660/eJHS.2022/031

Wang, N., Zhang, N., & Wang, M. (2006). Wireless sensors in agriculture and food industry - Recent development and future perspective. In Computers and Electronics in Agriculture (Vol. 50, Issue 1). https://doi.org/10.1016/j.compag.2005.09.003

Wang, S., Song, J., Qi, P., Yuan, C., Wu, H., Zhang, L., Liu, W., Liu, Y., & He, X. (2022). Design and development of orchard autonomous navigation spray system. Frontiers in Plant Science, 13. https://doi.org/10.3389/fpls.2022.960686

Zhang, P., Wang, S., Li, X., Chen, Z., Chen, X., Hu, Y., Zhang, H., Zhang, J., Li, M., Huang, Z., Li, Y., Li, L., Xu, X., Yang, Y., Song, H., Huo, H., Shi, Y., Hu, X., Wu, Y., … Zhang, Y. (2022). Orchard Energy Management to Improve Fruit Quality Based on the Internet of Things. Lecture Notes in Electrical Engineering, 942 LNEE. https://doi.org/10.1007/978-981-19-2456-9_68

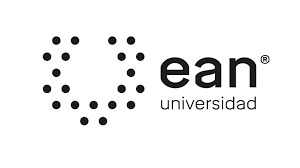
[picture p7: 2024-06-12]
0.Model/0.2. Sketch/SolidWorks Drawings/Imagen de WhatsApp 2024-06-11 a las 23.38.23_0f201395.jpg

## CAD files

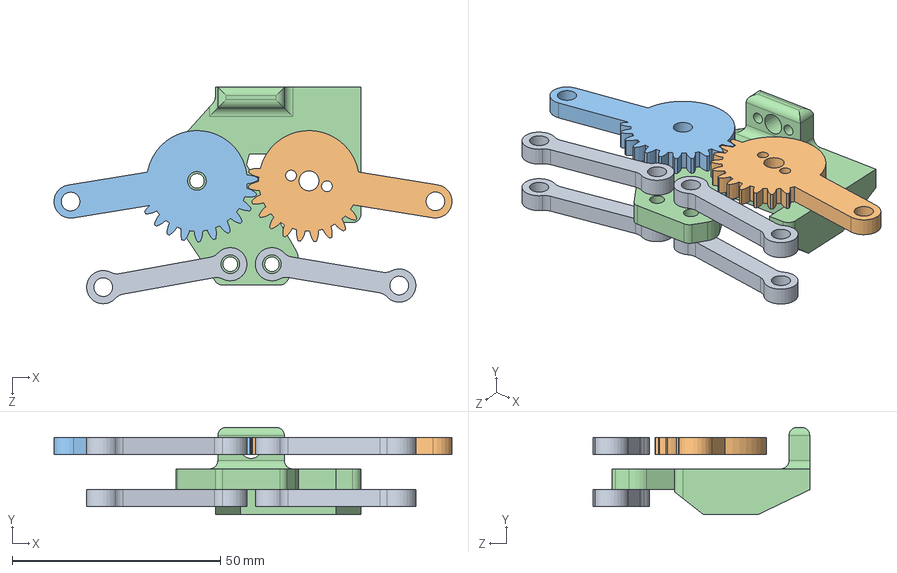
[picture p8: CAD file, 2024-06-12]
0.Model/0.1. Assembly/EnsamblePinza.SLDASM
95.6 x 21.0 x 52.0 mm
Gripper base mano3
gear1
gear2
grip link 1 x 4

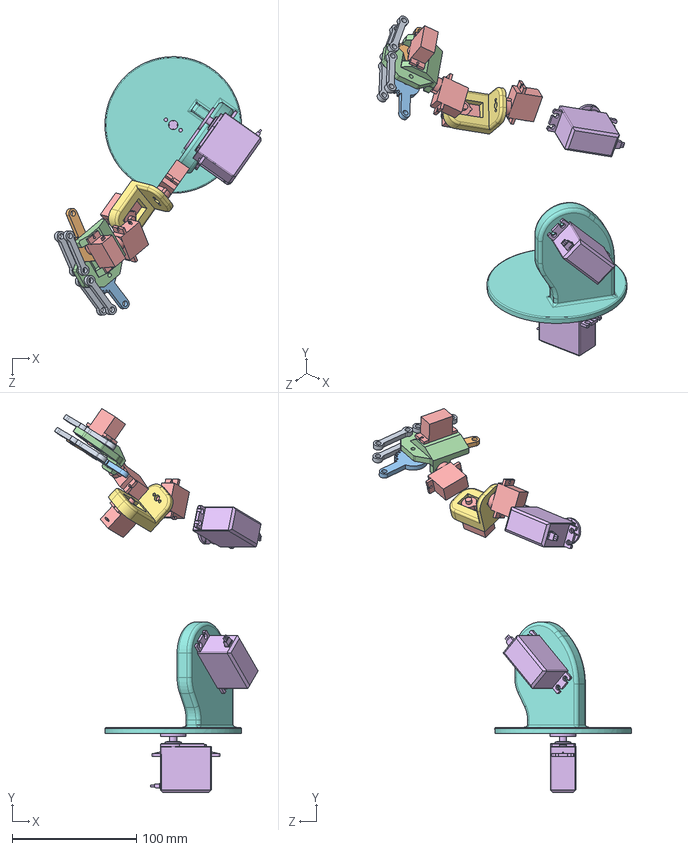
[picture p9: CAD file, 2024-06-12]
0.Model/0.1. Assembly/Ensamble.SLDASM
166.7 x 309.2 x 208.2 mm
Hombro
Mano1
Servo Motor MG996R x 3
Servo Motor Micro 9g x 4
Gripper base mano3
gear1
gear2
grip link 1 x 4

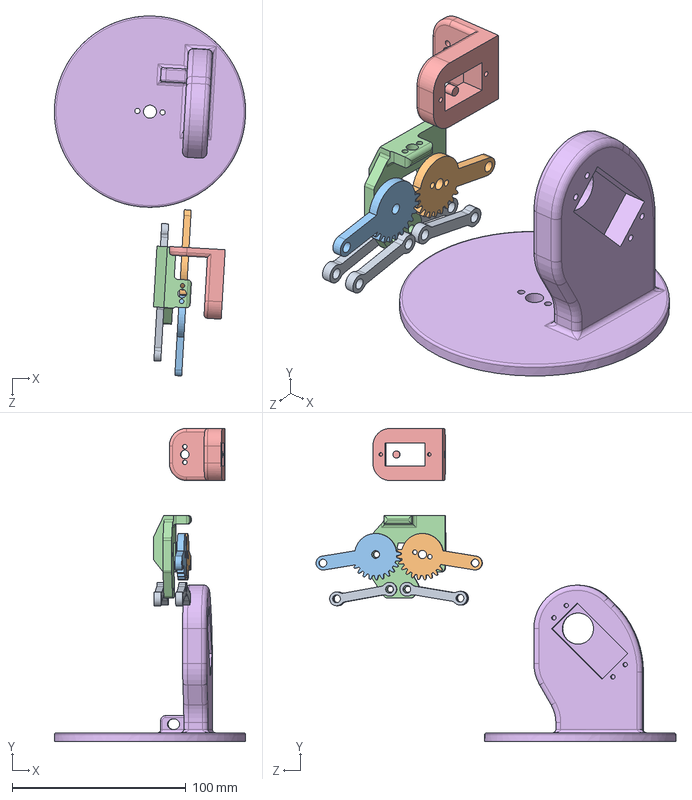
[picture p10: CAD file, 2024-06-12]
0.Model/0.1. Assembly/Ensamble2.SLDASM
109.9 x 180.1 x 207.0 mm
Hombro
Mano1
Gripper base mano3
gear1
gear2
grip link 1 x 4

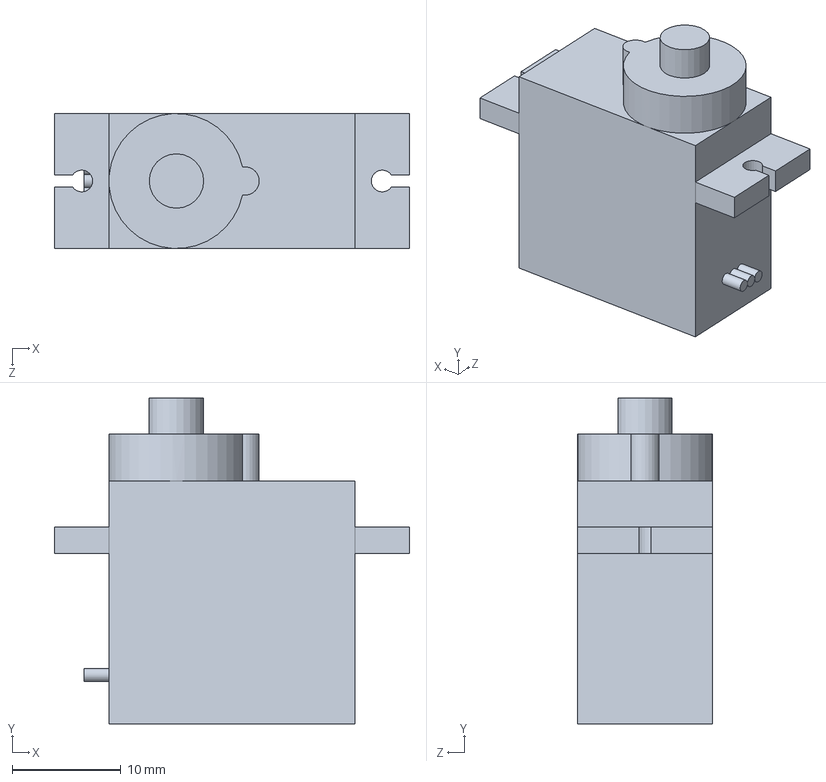
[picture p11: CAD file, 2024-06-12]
0.Model/0.0. Individual Parts/Servo Motor Micro 9g.SLDPRT
32.6 x 29.9 x 12.4 mm

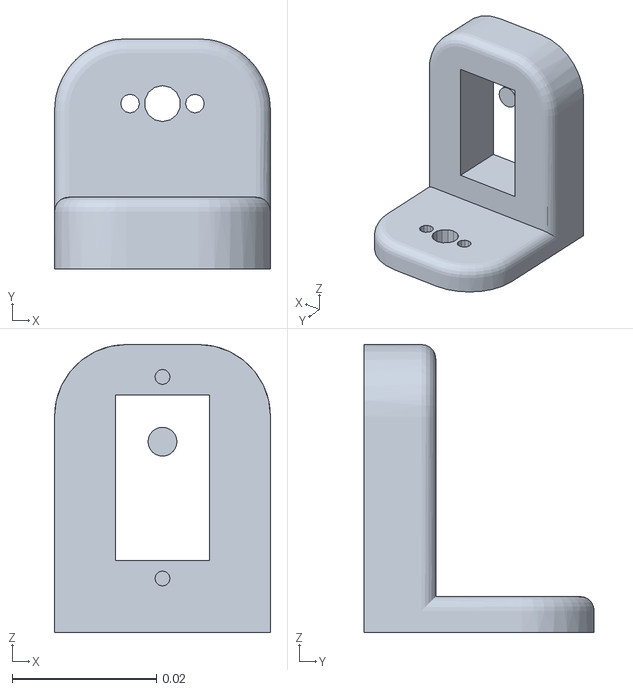
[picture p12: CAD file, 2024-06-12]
1.Software/Ensamblaje_urdf/meshes/Link_4.STL
0.03 x 0.032 x 0.04

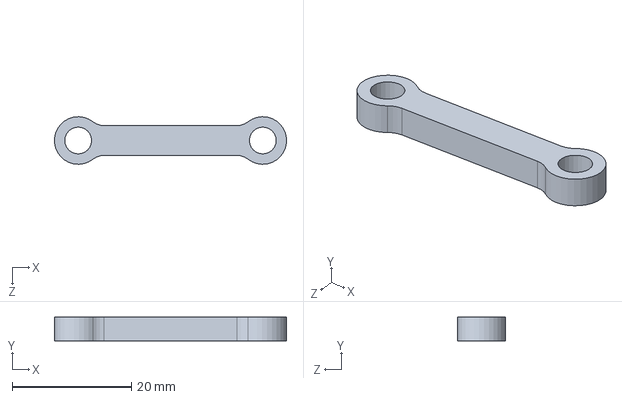
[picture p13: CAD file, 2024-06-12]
0.Model/0.0. Individual Parts/grip link 1.SLDPRT
39.0 x 4.00 x 8.00 mm

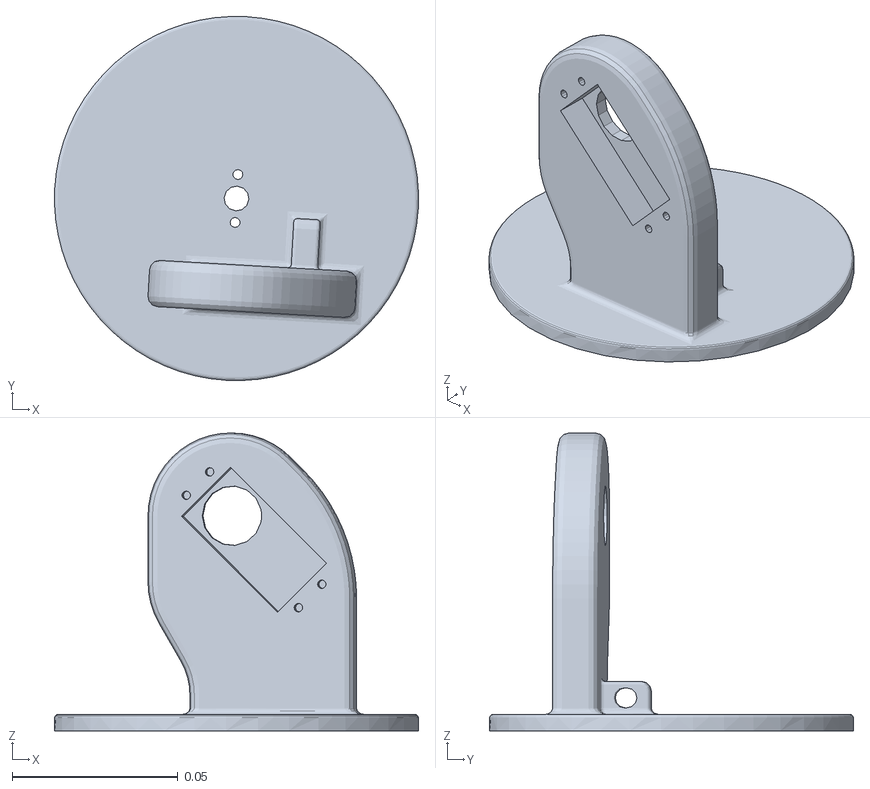
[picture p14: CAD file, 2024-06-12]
1.Software/Ensamblaje_urdf/meshes/Link_1.STL
0.11 x 0.11 x 0.09

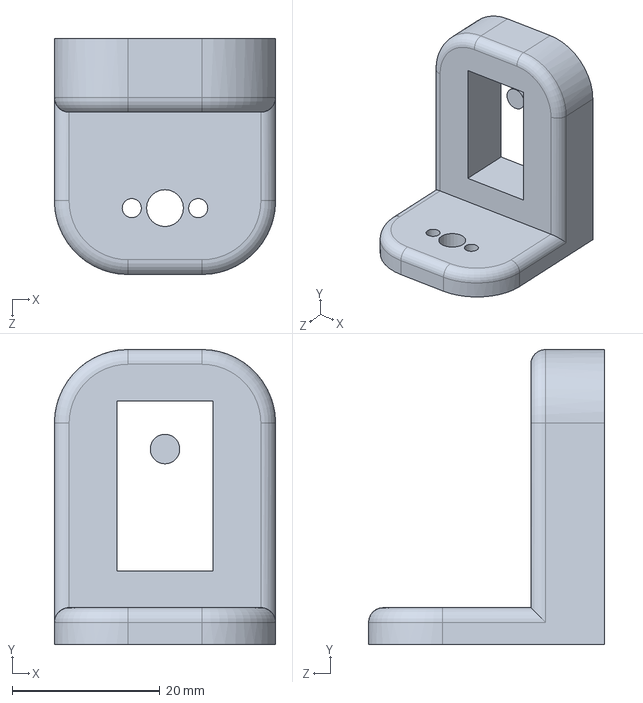
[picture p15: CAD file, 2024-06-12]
0.Model/0.0. Individual Parts/Mano1.SLDPRT
30.0 x 40.0 x 32.0 mm

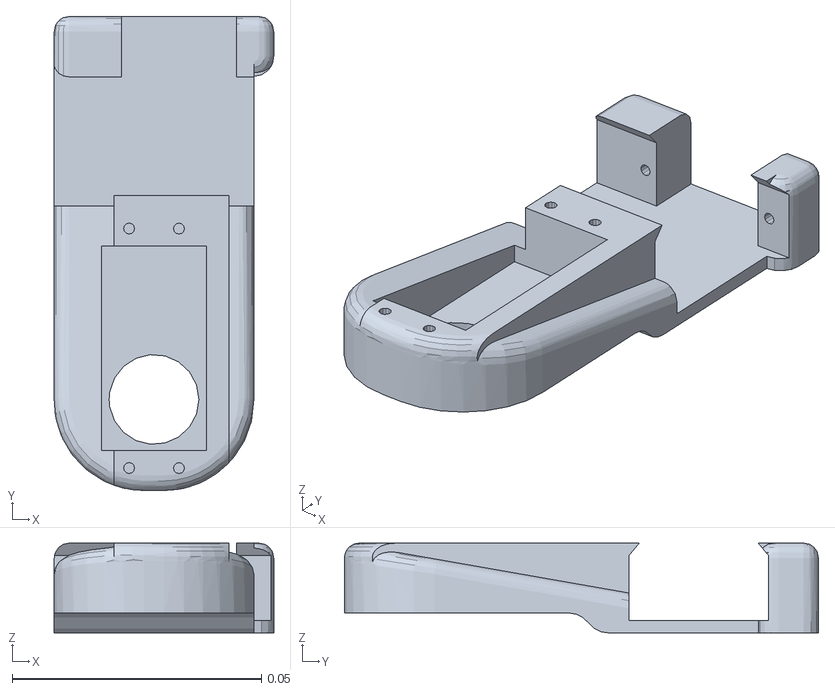
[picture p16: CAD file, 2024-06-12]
1.Software/Ensamblaje_urdf/meshes/Link_3.STL
0.044 x 0.095 x 0.018

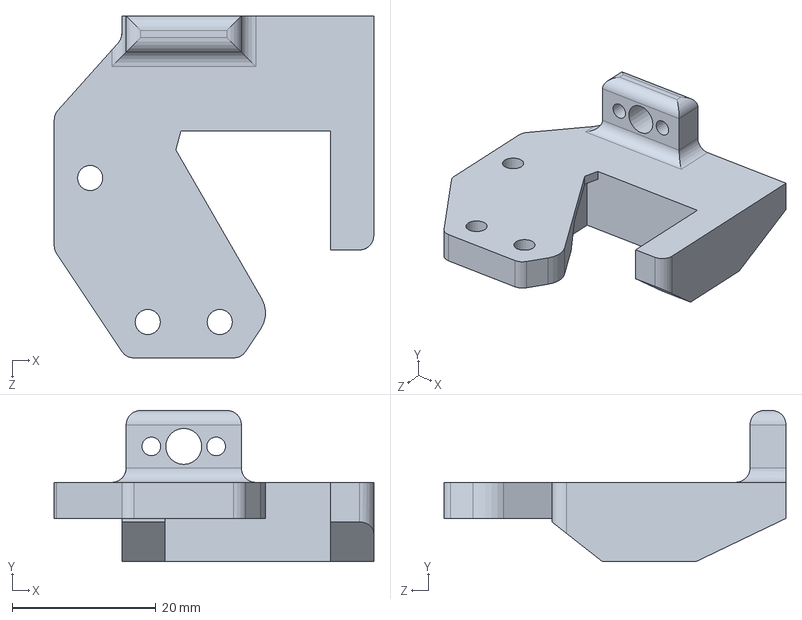
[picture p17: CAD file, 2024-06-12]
0.Model/0.0. Individual Parts/Gripper base mano3.SLDPRT
44.4 x 21.0 x 47.5 mm

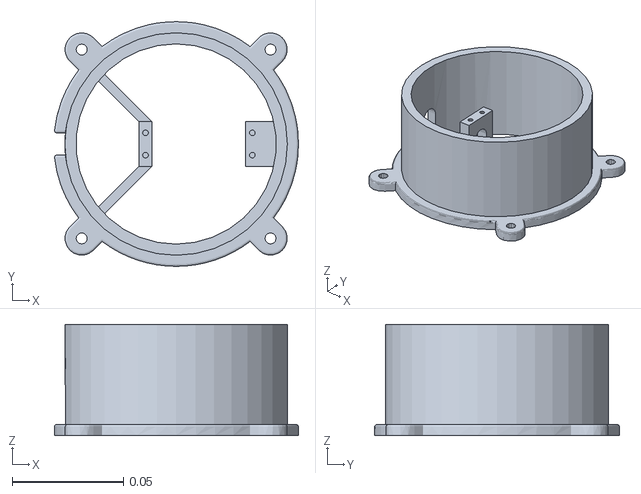
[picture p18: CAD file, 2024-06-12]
1.Software/Ensamblaje_urdf/meshes/base_link.STL
0.11 x 0.11 x 0.05

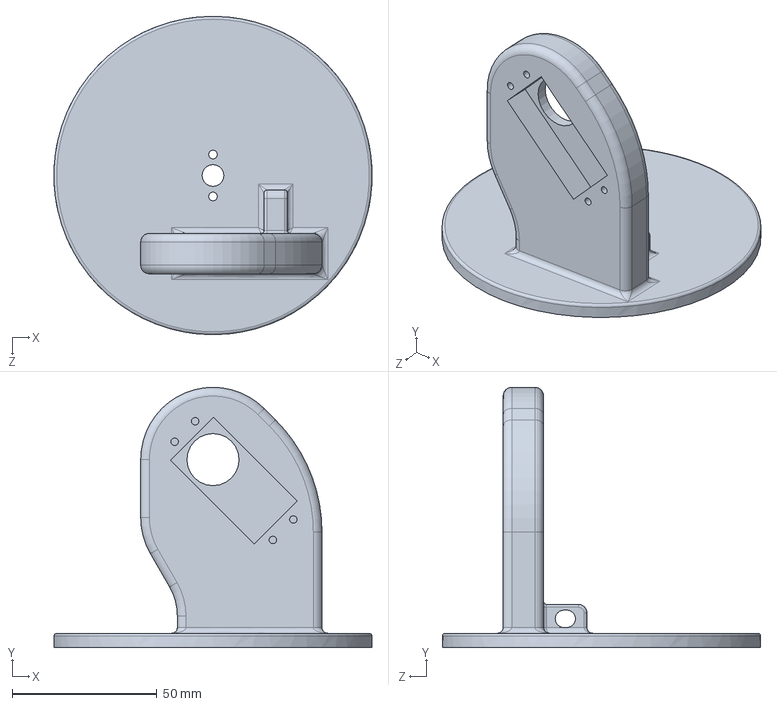
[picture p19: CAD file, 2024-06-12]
0.Model/0.0. Individual Parts/Hombro.SLDPRT
109.9 x 90.0 x 110.0 mm

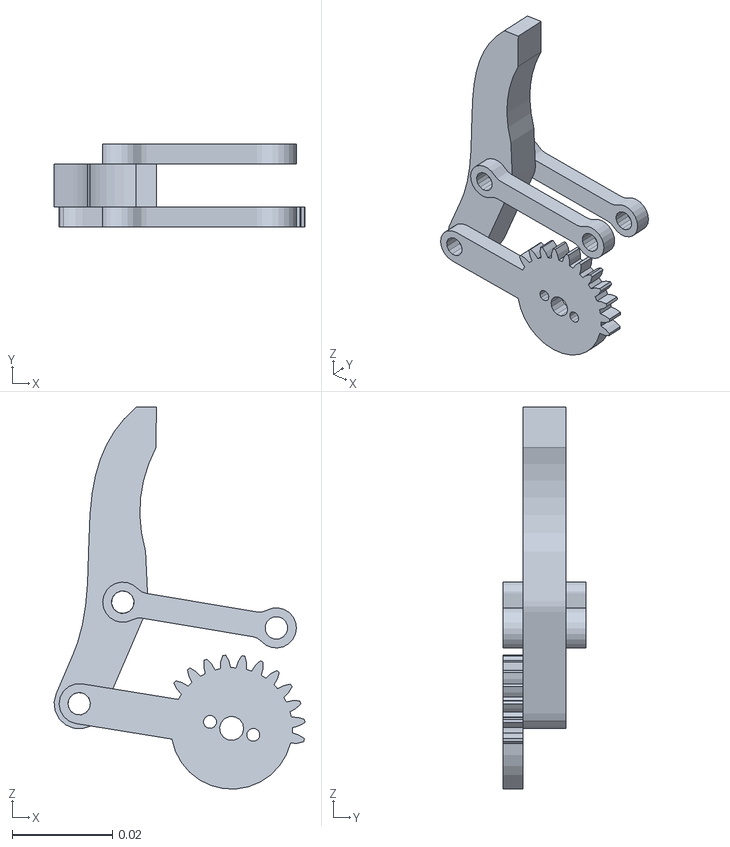
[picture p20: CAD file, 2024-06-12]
1.Software/Ensamblaje_urdf/meshes/Gear_1.STL
0.0499 x 0.0165 x 0.076

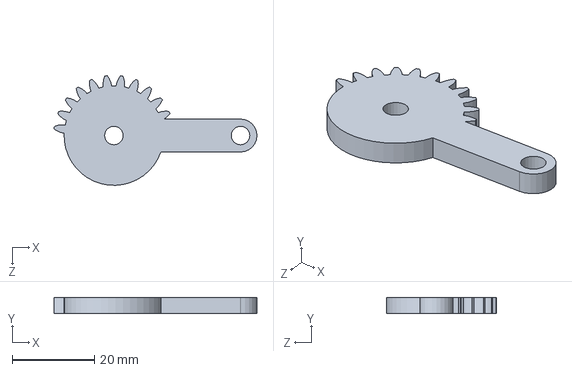
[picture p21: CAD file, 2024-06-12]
0.Model/0.0. Individual Parts/gear1.SLDPRT
49.3 x 4.00 x 26.6 mm

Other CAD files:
1.Software/Ensamblaje_urdf/meshes/Gear_2.STL
0.Model/0.0. Individual Parts/gear2.SLDPRT
1.Software/Ensamblaje_urdf/meshes/Link_2.STL
0.Model/0.0. Individual Parts/Servo Motor MG996R.SLDPRT
0.Model/0.0. Individual Parts/BaseCentral.SLDPRT
0.Model/0.0. Individual Parts/Brazo.SLDPRT
0.Model/0.0. Individual Parts/Codo.SLDPRT
0.Model/0.0. Individual Parts/Gripper 1.SLDPRT
0.Model/0.0. Individual Parts/Mano2.SLDPRT
0.Model/0.2. Sketch/SolidWorks Drawings/BaseCentral.SLDDRW
0.Model/0.2. Sketch/SolidWorks Drawings/Brazo.SLDDRW
0.Model/0.2. Sketch/SolidWorks Drawings/Codo.SLDDRW
0.Model/0.2. Sketch/SolidWorks Drawings/Ensamble1_brazo.SLDDRW
0.Model/0.2. Sketch/SolidWorks Drawings/Ensamble_explosionado_robot.SLDDRW
0.Model/0.2. Sketch/SolidWorks Drawings/Gripper 1.SLDDRW
0.Model/0.2. Sketch/SolidWorks Drawings/Gripper base mano3.SLDDRW
0.Model/0.2. Sketch/SolidWorks Drawings/Hombro.SLDDRW
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

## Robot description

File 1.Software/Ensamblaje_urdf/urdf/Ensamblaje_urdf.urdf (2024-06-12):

<?xml version="1.0" encoding="utf-8"?>
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
<robot name="Ensamblaje_urdf">
  <link name="base_link">
    <inertial>
      <origin xyz="0.0322200031928641 -0.0972638754653942 0.0682998161287198" rpy="0 0 0" />
      <mass value="0.0928157775981503" />
      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
    </inertial>
    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
  </link>
  <link name="Link_1">
    <inertial>
      <origin xyz="0.00278772445519503 -0.0141950931892659 0.0733291965973253" rpy="0 0 0" />
      <mass value="0.10003518295232" />
      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
    </inertial>
    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
  </link>
  <joint name="Joint_1" type="revolute">
    <origin xyz="0.030772 -0.097264 0.046511" rpy="0 0 1.5708" />
    <parent link="base_link" />
    <child link="Link_1" />
    <axis xyz="0 0 1" />
    <limit lower="-3.141" upper="3.141" effort="0" velocity="0" />
    <dynamics damping="0" friction="0.1" />
    <safety_controller k_position="0" k_velocity="0" />
  </joint>
  <link name="Link_2">
    <inertial>
      <origin xyz="0.000231483465368554 0.0448524809778406 -0.00620921823174211" rpy="0 0 0" />
      <mass value="0.0383597436321771" />
      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
    </inertial>
    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
  </link>
  <joint name="Joint_2" type="revolute">
    <origin xyz="-0.001086 -0.018969 0.115" rpy="1.5708 0 -0.057192" />
    <parent link="Link_1" />
    <child link="Link_2" />
    <axis xyz="0 0 1" />
    <limit lower="-0.5236" upper="0.5236" effort="0" velocity="0" />
    <dynamics damping="0" friction="0.1" />
  </joint>
  <link name="Link_3">
    <inertial>
      <origin xyz="0.00069688652357075 0.0285969895596061 0.00472408915627993" rpy="0 0 0" />
      <mass value="0.022856319141086" />
      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
    </inertial>
    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
  </link>
  <joint name="Joint_3" type="revolute">
    <origin xyz="0 0.1 0" rpy="0 0 1.5708" />
    <parent link="Link_2" />
    <child link="Link_3" />
    <axis xyz="0 0 1" />
    <limit lower="-1.57" upper="0.349" effort="0" velocity="0" />
    <dynamics damping="0" friction="0.1" />
  </joint>
  <link name="Link_4">
    <inertial>
      <origin xyz="-3.78071672302305E-08 -0.0141973642744543 0.0094781833411583" rpy="0 0 0" />
      <mass value="0.0113759959526115" />
      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
    </inertial>
    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
  </link>
  <joint name="Joint_4" type="revolute">
    <origin xyz="0.0001 0.08175 0.0057" rpy="-1.5708 0 0" />
    <parent link="Link_3" />
    <child link="Link_4" />
    <axis xyz="0 0 1" />
    <limit lower="-3.141" upper="3.141" effort="0" velocity="0" />
    <dynamics damping="0" friction="0.1" />
  </joint>
  <link name="Link_5">
    <inertial>
      <origin xyz="0.0208486821058811 -0.00257109803423941 -0.00309788620131497" rpy="0 0 0" />
      <mass value="0.0107896310002059" />
      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
    </inertial>
    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
  </link>
  <joint name="Joint_5" type="revolute">
    <origin xyz="0 -0.008 0.0215" rpy="-1.5708 0 -3.1416" />
    <parent link="Link_4" />
    <child link="Link_5" />
    <axis xyz="0 0 1" />
    <limit lower="-3.141" upper="0.174" effort="0" velocity="0" />
    <dynamics damping="0" friction="0.1" />
  </joint>
  <link name="Link_6">
    <inertial>
      <origin xyz="-0.00419644542521305 0.00847430858350158 0.0175660111897017" rpy="0 0 0" />
      <mass value="0.010244216345748" />
      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
    </inertial>
    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
  </link>
  <joint name="Joint_6" type="revolute">
    <origin xyz="0.035 -0.0001 -0.0083" rpy="-1.5708 0 -1.5708" />
    <parent link="Link_5" />
    <child link="Link_6" />
    <axis xyz="0 0 1" />
    <limit lower="-3.141" upper="3.141" effort="0" velocity="0" />
    <dynamics damping="0" friction="0.1" />
  </joint>
  <link name="Gear_1">
    <inertial>
      <origin xyz="-0.0159803230581214 0.00254770351597362 0.0220162492775055" rpy="0 0 0" />
      <mass value="0.00932837809791009" />
      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
    </inertial>
    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
  </link>
  <joint name="joint_gear1" type="revolute">
    <origin xyz="-0.0139 0.0015 0.0225" rpy="0 0 0" />
    <parent link="Link_6" />
    <child link="Gear_1" />
    <axis xyz="0 1 0" />
    <limit lower="-0.523" upper="0.523" effort="0" velocity="0" />
  </joint>
  <link name="Gear_2">
    <inertial>
      <origin xyz="0.0166748141124543 0.00652318437293002 0.0220996277108557" rpy="0 0 0" />
      <mass value="0.00937899887669891" />
      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
    </inertial>
    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
  </link>
  <joint name="Joint_gear2" type="revolute">
    <origin xyz="0.013 -0.0025 0.0225" rpy="0 0 0" />
    <parent link="Link_6" />
    <child link="Gear_2" />
    <axis xyz="0 1 0" />
    <limit lower="-0.523" upper="0.523" effort="0" velocity="0" />
  </joint>
</robot>

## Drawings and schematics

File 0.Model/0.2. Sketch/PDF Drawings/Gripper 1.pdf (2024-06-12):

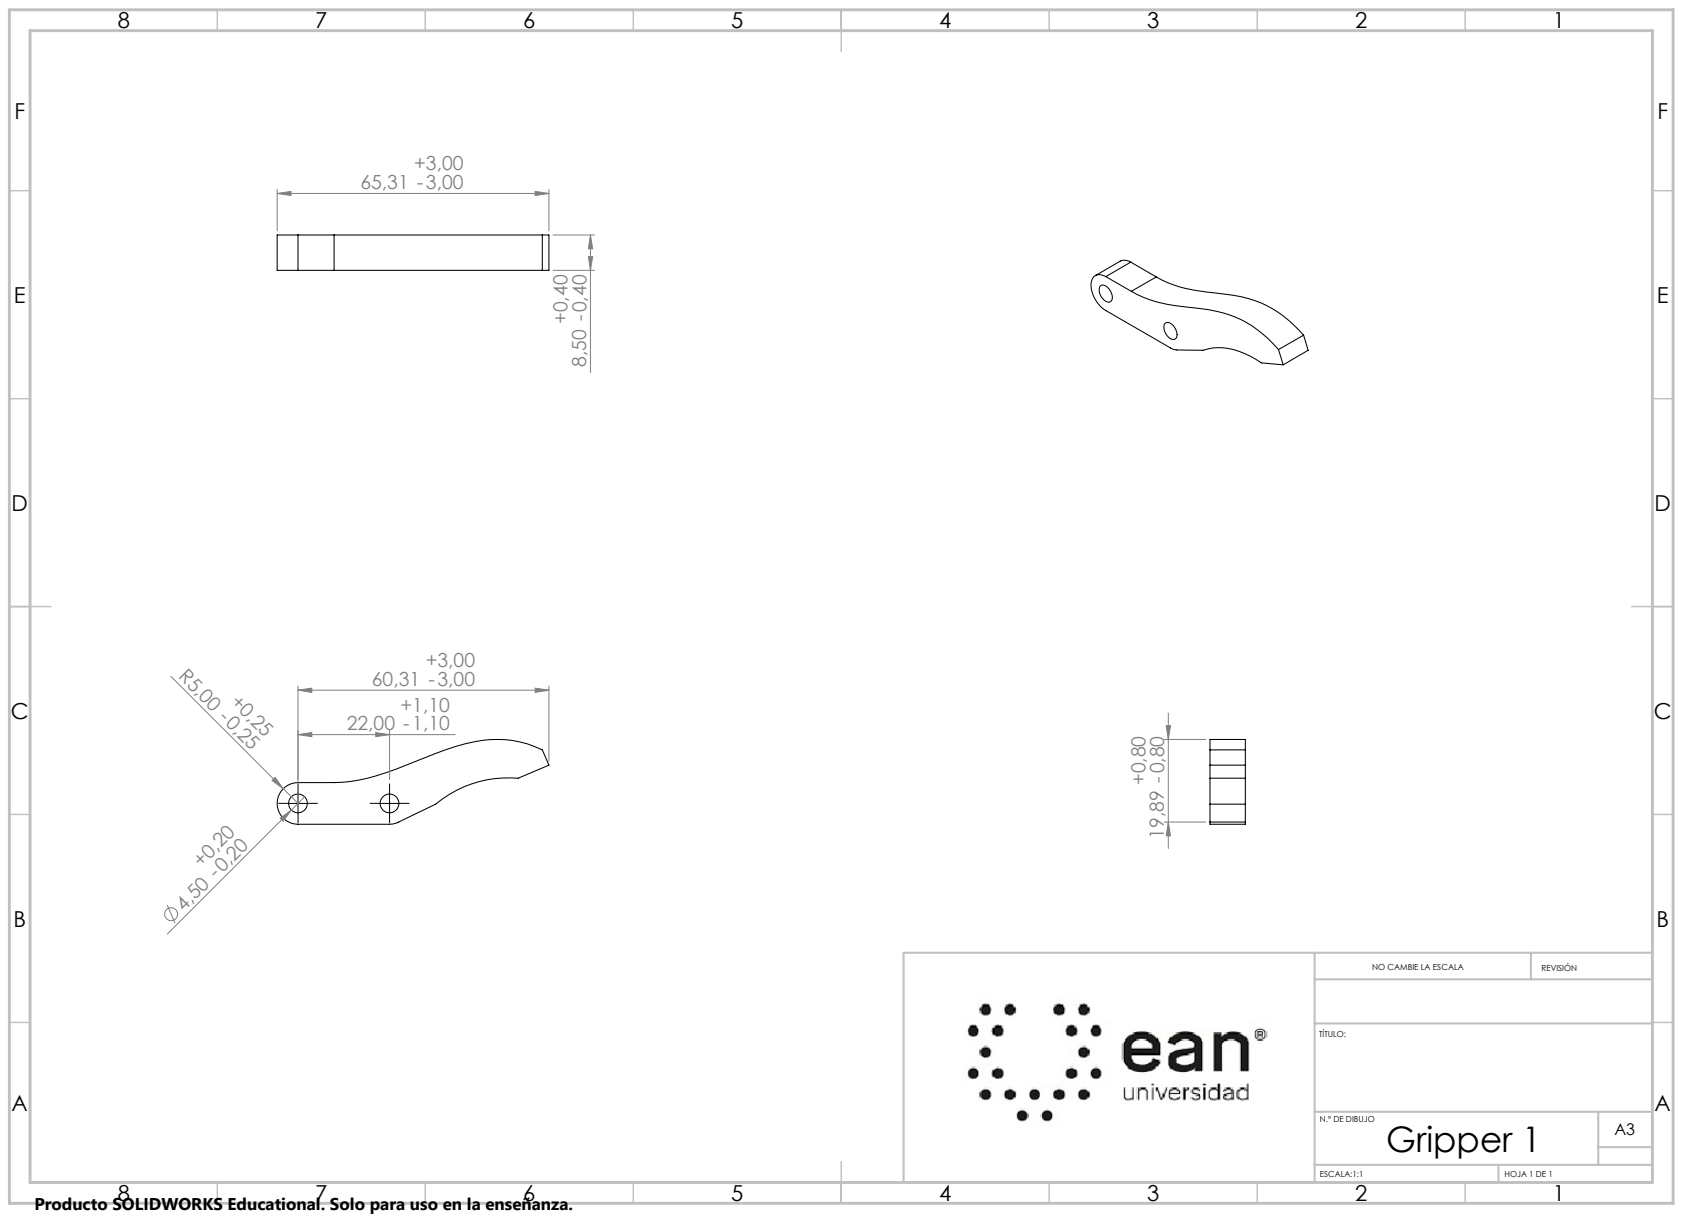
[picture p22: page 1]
NO CAMBIE LA ESCALA; REVISIÓN; N.º DE DIBUJO; ESCALA:1:1; HOJA 1 DE 1; Gripper 1

Producto SOLIDWORKS Educational. Solo para uso en la enseñanza.

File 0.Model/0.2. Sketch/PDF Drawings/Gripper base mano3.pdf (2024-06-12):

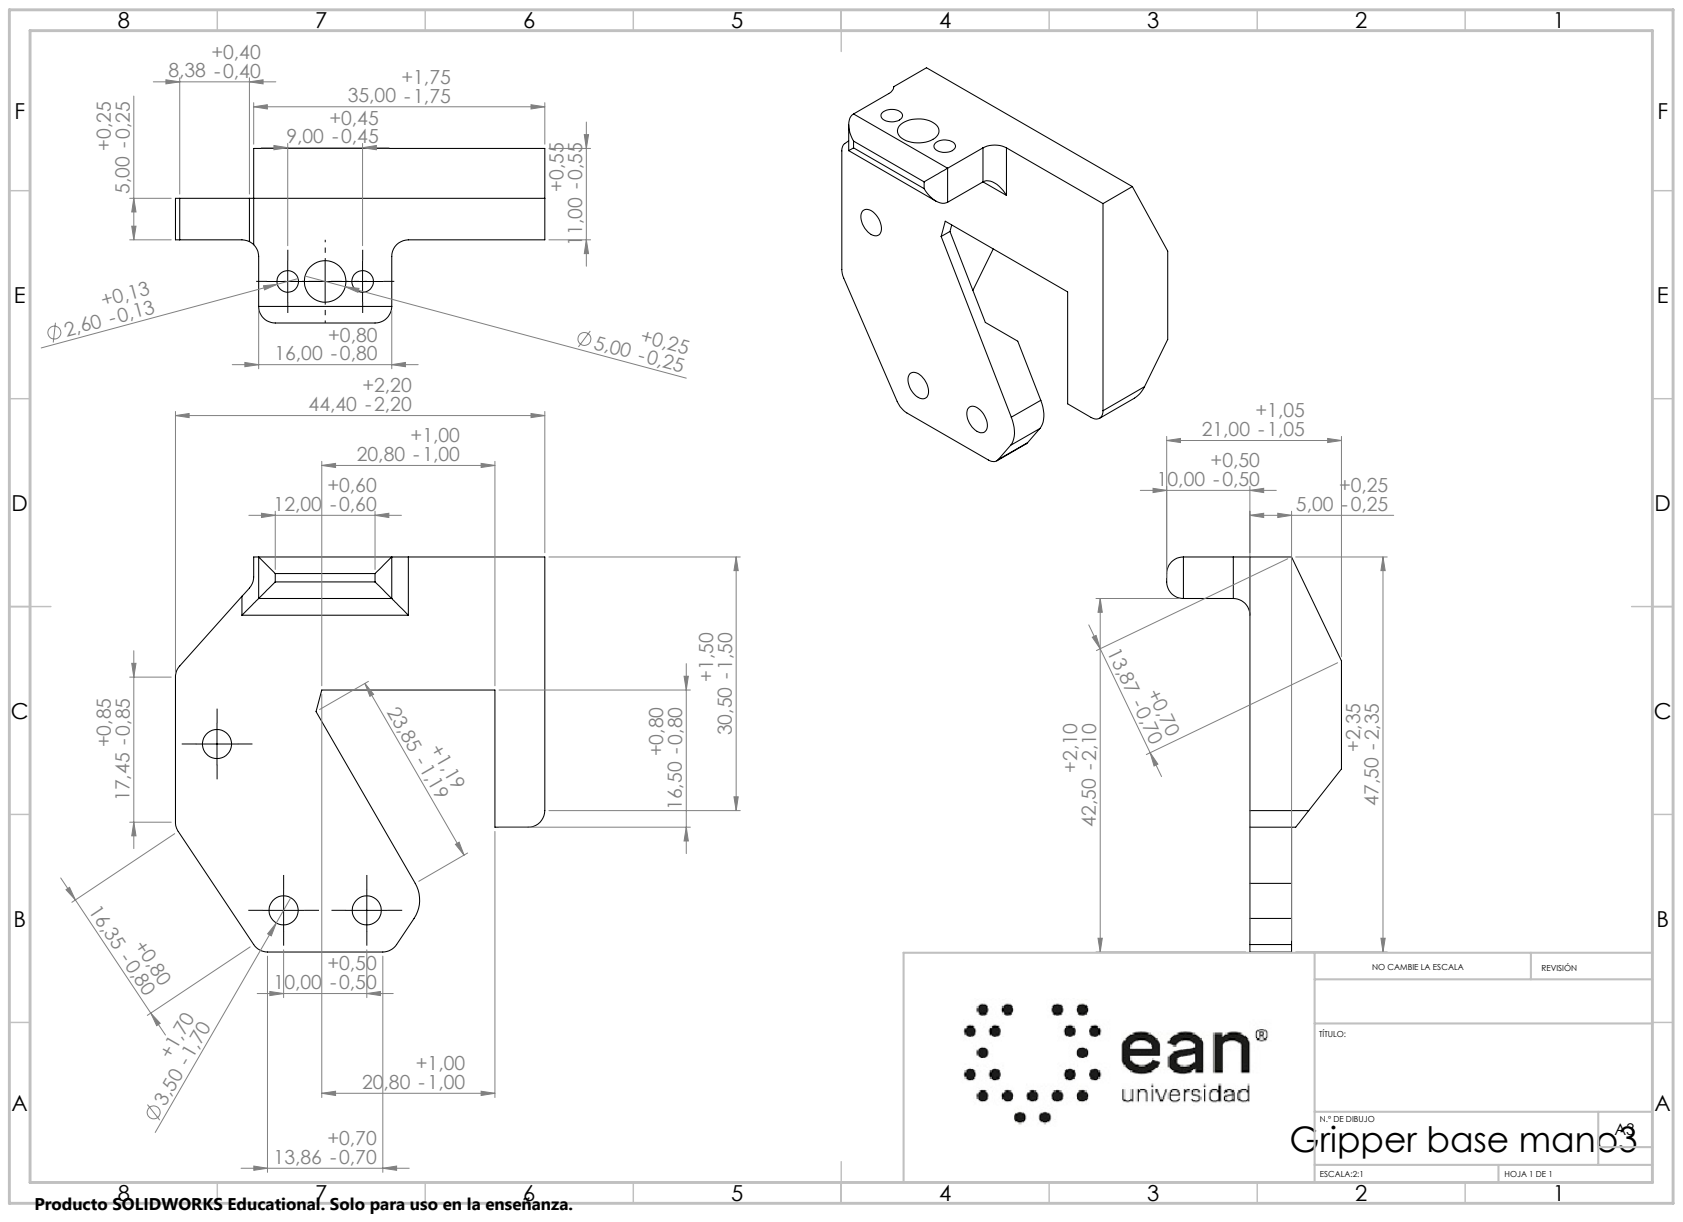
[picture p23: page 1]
NO CAMBIE LA ESCALA; REVISIÓN; N.º DE DIBUJO; ESCALA:2:1; HOJA 1 DE 1; Gripper base mano3

Producto SOLIDWORKS Educational. Solo para uso en la enseñanza.

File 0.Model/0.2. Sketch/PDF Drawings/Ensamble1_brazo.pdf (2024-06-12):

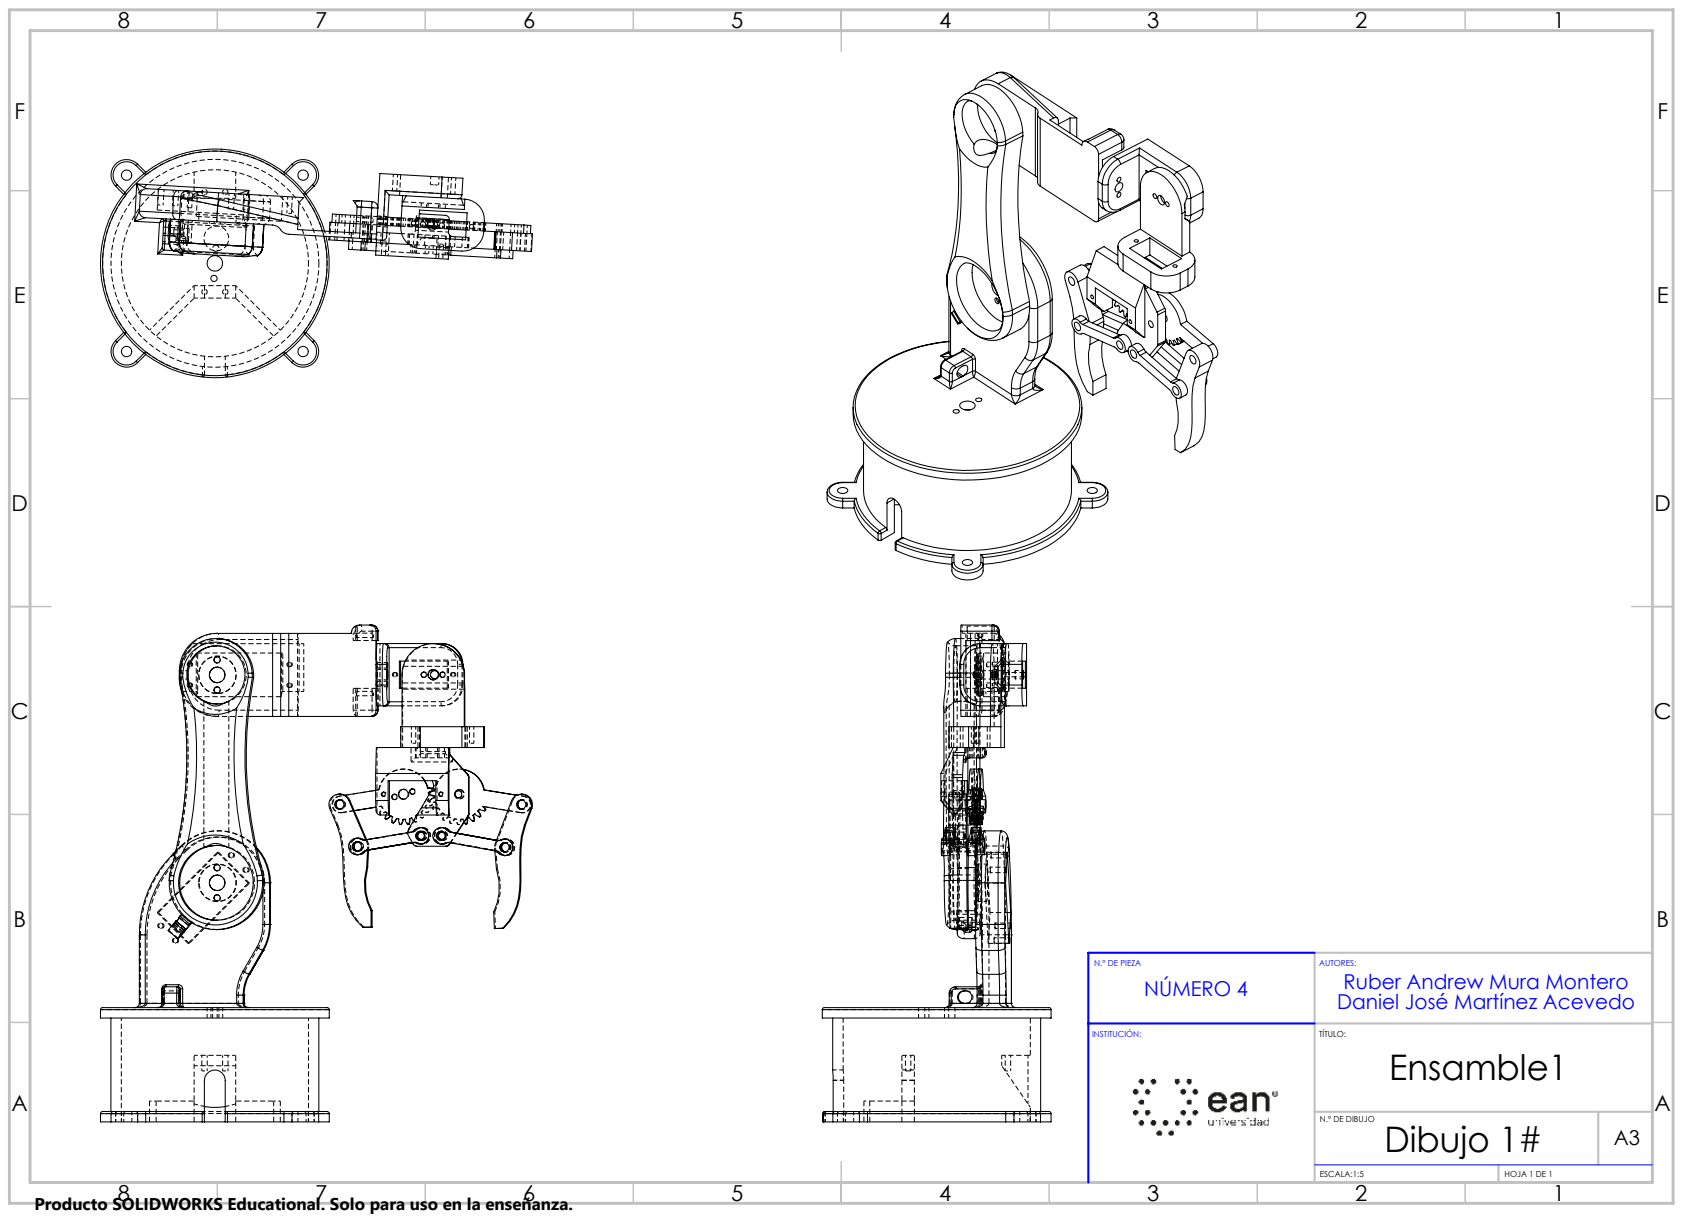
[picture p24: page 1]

N.º DE PIEZA NÚMERO 4 | AUTORES: Ruber Andrew Mura Montero Daniel José Martínez Acevedo

INSTITUCIÓN: | TÍTULO: Ensamble1

N.º DE DIBUJO Dibujo 1# | A3

ESCALA:1:5 | HOJA 1 DE 1

Producto SOLIDWORKS Educational. Solo para uso en la enseñanza.

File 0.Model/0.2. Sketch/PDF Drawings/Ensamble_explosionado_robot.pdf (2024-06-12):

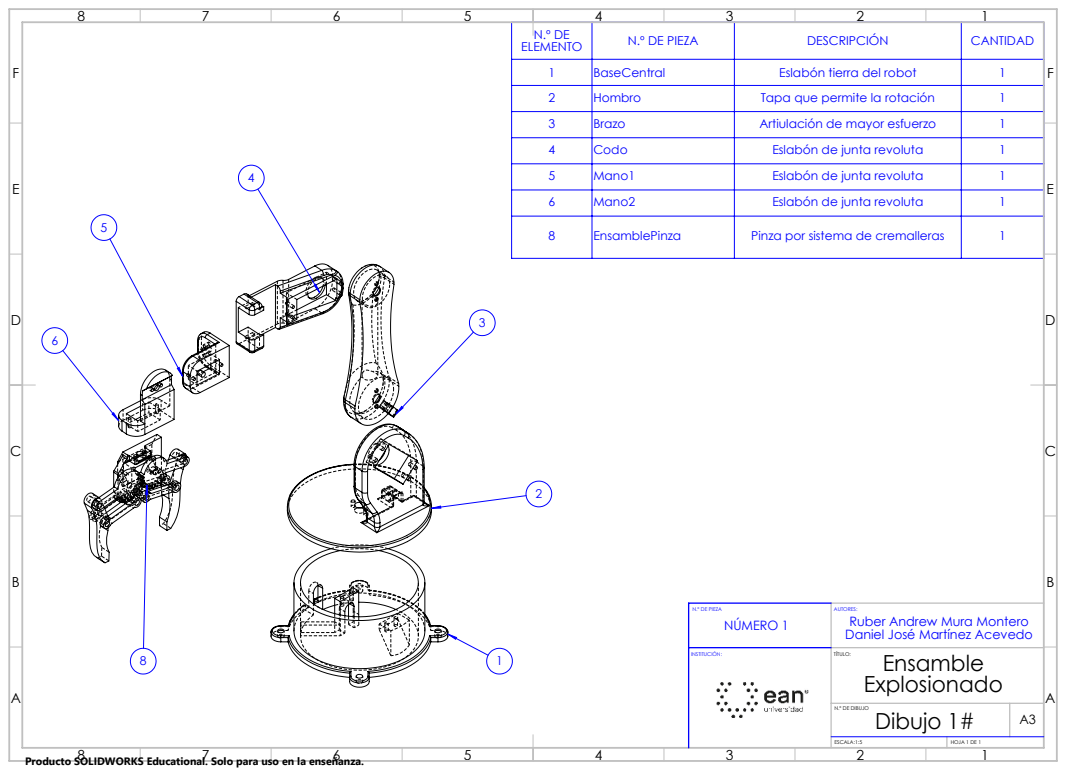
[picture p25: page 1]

ELEMENTO | N.º DE PIEZA | DESCRIPCIÓN | CANTIDAD
1 | BaseCentral | Eslabón tierra del robot | 1
2 | Hombro | Tapa que permite la rotación | 1
3 | Brazo | Artiulación de mayor esfuerzo | 1
4 | Codo | Eslabón de junta revoluta | 1
5 | Mano1 | Eslabón de junta revoluta | 1
6 | Mano2 | Eslabón de junta revoluta | 1

8 | EnsamblePinza | Pinza por sistema de cremalleras | 1

N.º DE PIEZA NÚMERO 1 | AUTORES: Ruber Andrew Mura Montero Daniel José Martínez Acevedo

INSTITUCIÓN: | Ensamble TÍTULO: Explosionado

N.º DE DIBUJO Dibujo 1# | A3

ESCALA:1:5 | HOJA 1 DE 1

Producto SOLIDWORKS Educational. Solo para uso en la enseñanza.

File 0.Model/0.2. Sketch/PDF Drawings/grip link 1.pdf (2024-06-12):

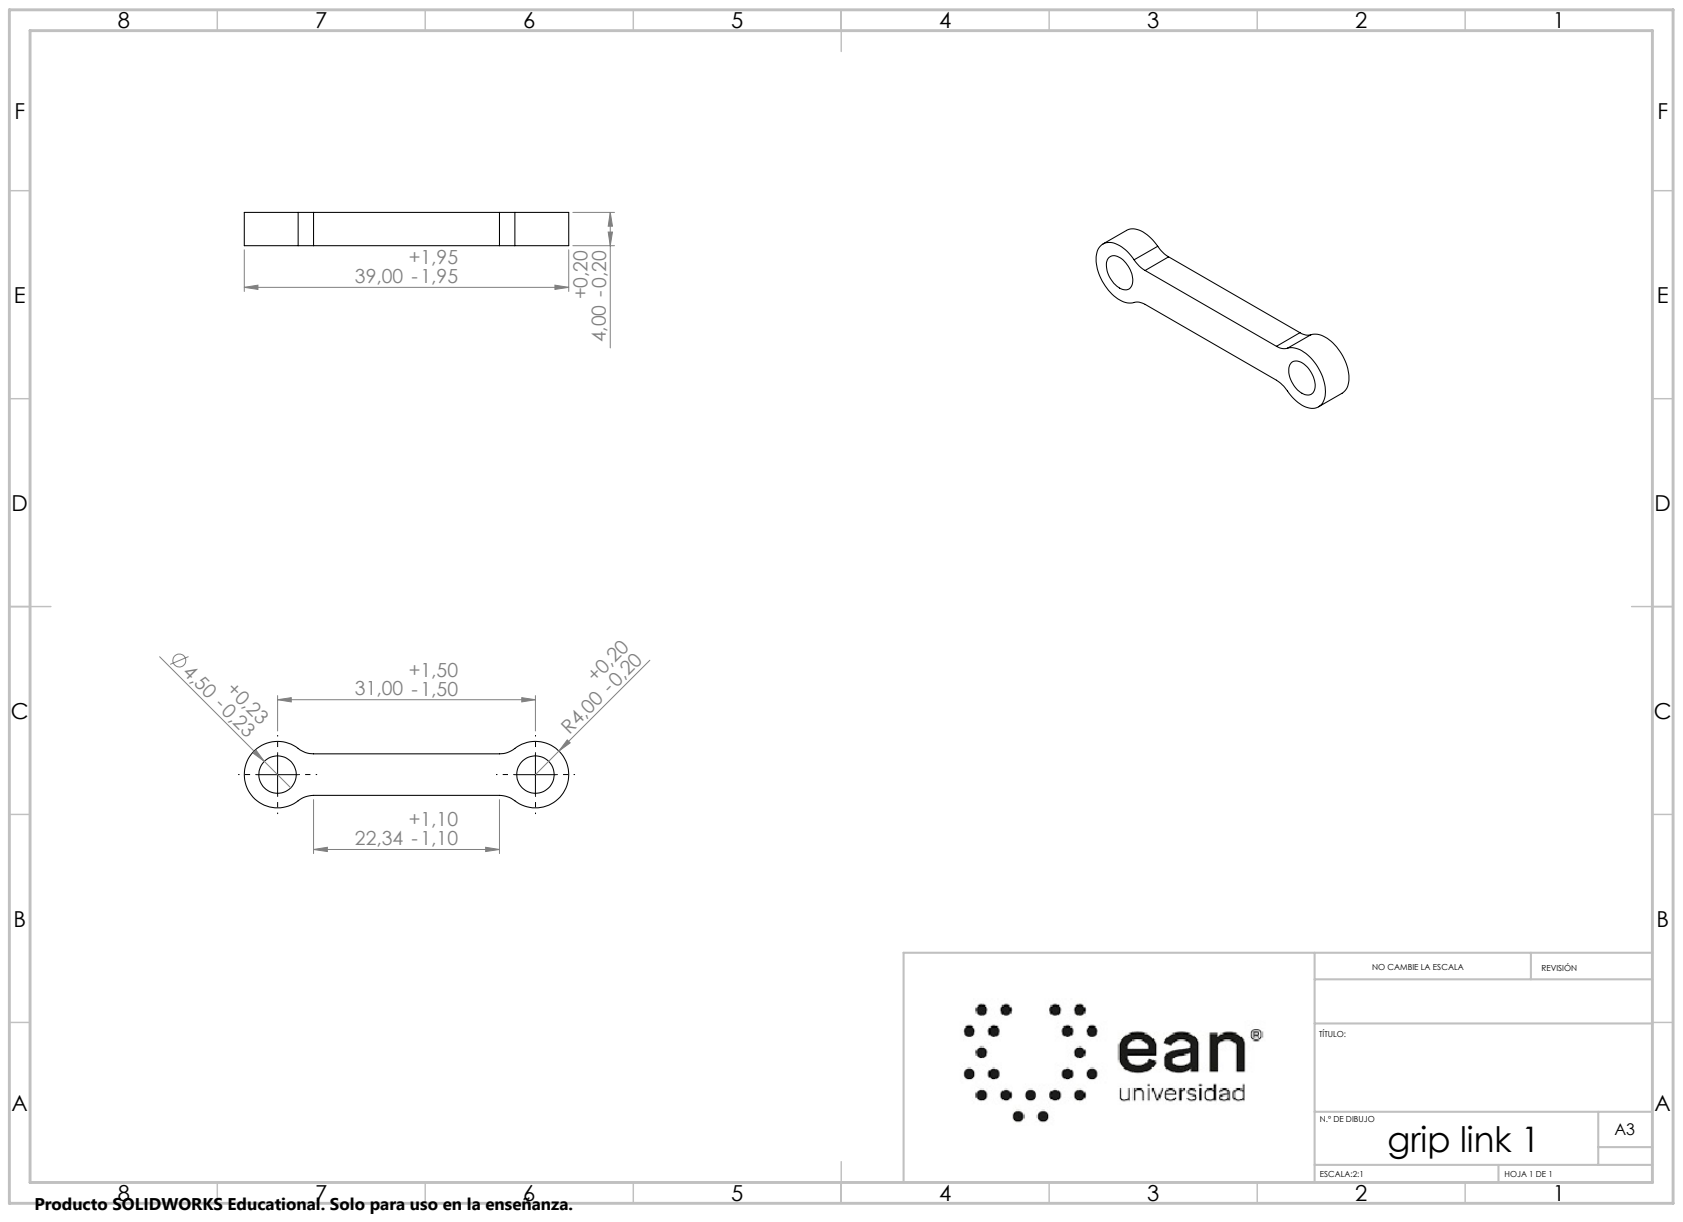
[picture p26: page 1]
NO CAMBIE LA ESCALA; REVISIÓN; N.º DE DIBUJO; ESCALA:2:1; HOJA 1 DE 1; grip link 1

Producto SOLIDWORKS Educational. Solo para uso en la enseñanza.

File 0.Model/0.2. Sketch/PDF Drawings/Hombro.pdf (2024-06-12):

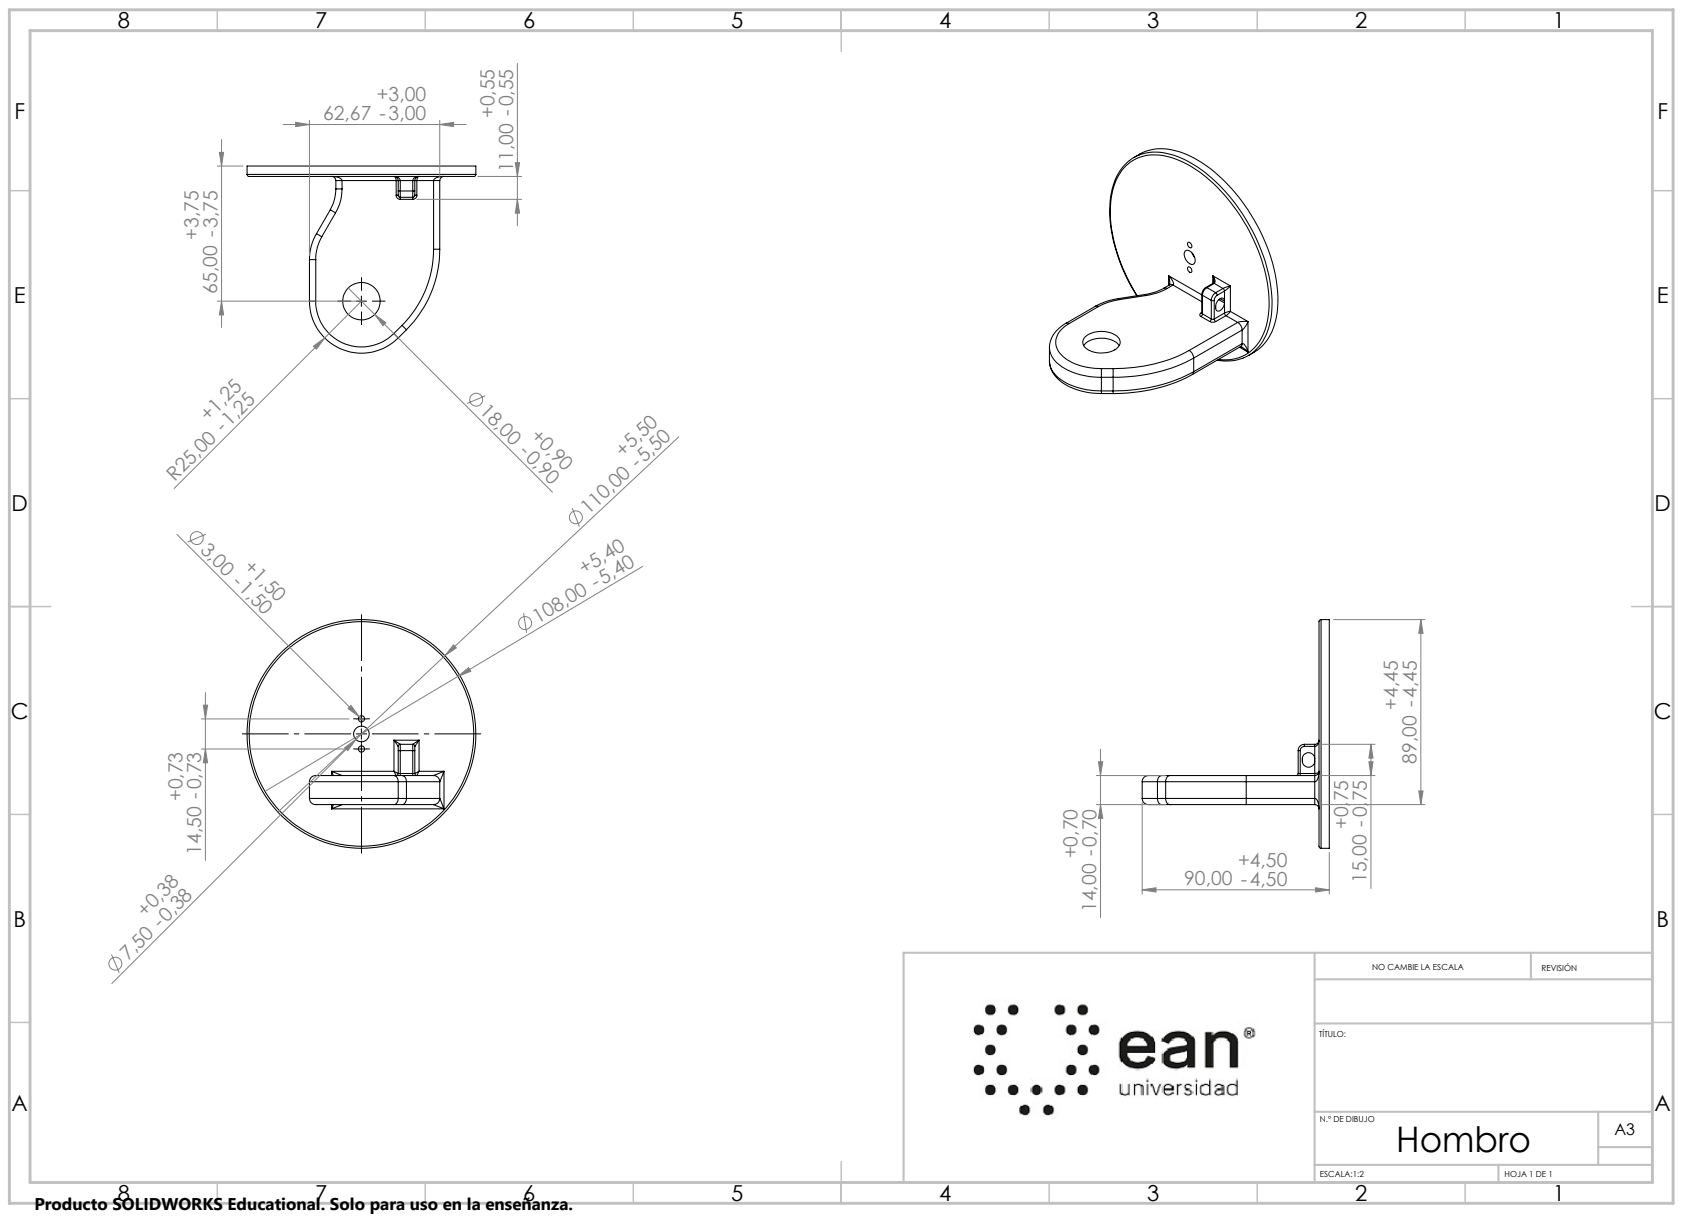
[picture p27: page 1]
NO CAMBIE LA ESCALA; REVISIÓN; N.º DE DIBUJO; ESCALA:1:2; HOJA 1 DE 1

Producto SOLIDWORKS Educational. Solo para uso en la enseñanza.

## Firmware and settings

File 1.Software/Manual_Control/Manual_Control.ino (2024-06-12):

#include <Wire.h>
#include <Adafruit_PWMServoDriver.h>

Adafruit_PWMServoDriver pwm;

// Definición de los límites de pulso para los servos
const int SERVOMIN = 150; // Pulso 'ínimo' en microsegundos
const int SERVOMAX = 600; // Pulso 'áximo' en microsegundos

// Limites específicos de cada servo
enum ServoLimits {
  SERVO0_MIN = 0,
  SERVO0_MAX = 180,
  SERVO1_MIN = 0,
  SERVO1_MAX = 85,
  SERVO2_MIN = 0,
  SERVO2_MAX = 90,
  SERVO3_MIN = 2,
  SERVO3_MAX = 90,
  SERVO4_MIN = 0,
  SERVO4_MAX = 80
};

bool automationActive = false;

void setup() {
  Serial.begin(9600);
  Serial.println("Iniciando PCA9685...");
  
  pwm.begin();
  pwm.setPWMFreq(60);  // Frecuencia PWM estándar para servos
  
  Serial.println("Presiona 'Y' para comenzar la automatización o 'S' para detenerla.");
}

void loop() {
  if (Serial.available()) {
    char input = Serial.read();
    
    if (input == 'Y' || input == 'y') {
      automationActive = true;
      executeSequence();
    }
    
    if (input == 'S' || input == 's') {
      automationActive = false;
      Serial.println("Automatización detenida.");
    }
  }
}

void moveServo(int servo, int angle) {
  int pulseLength = map(angle, 0, 180, SERVOMIN, SERVOMAX);
  pwm.setPWM(servo, 0, pulseLength);
  Serial.print("Moviendo servo ");
  Serial.print(servo);
  Serial.print(" a ");
  Serial.print(angle);
  Serial.println(" grados.");
}

void executeSequence() {
  // Posición inicial
  int initialAngles[] = {90, 0, 0, 2, 80};
  for (int i = 0; i < 5; i++) {
    moveServo(i, initialAngles[i]);
  }
  delay(1000);

  // Mover brazo a la posición del objeto
  int objectAngles[] = {90, 45, 45, 45, 0};
  for (int i = 0; i < 5; i++) {
    moveServo(i, objectAngles[i]);
  }
  delay(1000);

  // Mover brazo a la posición de destino
  int destinationAngles[] = {150, 20, 20, 20, 80};
  for (int i = 0; i < 5; i++) {
    moveServo(i, destinationAngles[i]);
  }
  delay(1000);

  // Regresar a la posición inicial
  for (int i = 0; i < 5; i++) {
    moveServo(i, initialAngles[i]);
  }
}

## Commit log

2024-06-12 ADD - Initial folders
    create and add the folders of the project and include the solidworks parts on the model file as their assembly too, changing the Read.me introduction
    [BaseCentral.SLDPRT, Brazo.SLDPRT, Codo.SLDPRT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]
2024-06-12 ADD - Software manual control
    Agged a ino code manual control for the robotic arm and samples to every empty folder, also add more information to the md file
2024-06-12 ADD Skectch and md
    Adding the scketch files in solidworks format and also in pdf for easy review, also change the md file to provide mor infor about the project
    [BaseCentral.SLDDRW, Brazo.SLDDRW, Codo.SLDDRW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]

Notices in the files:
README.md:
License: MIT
